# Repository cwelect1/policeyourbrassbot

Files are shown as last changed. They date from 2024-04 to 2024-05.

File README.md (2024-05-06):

# Police Your Brass Bot
A robotics project for <a href="https://courses.dce.harvard.edu/?details&srcdb=202403&crn=34560" target="_blank">DGMD E-17 Spring 2024</a> that collects spent shell casings (brass).

Collecting brass at the firing range is a tedious task that no one seems to enjoy.
There are <a href="https://ammoupusa.com/" target="_blank">manual</a> options that exist to complete the job, but with modern advances in technology an automated solution is in order.

We are taking 2 approaches to prototyping that solution. 
1. Create an RC Car like robot operated via Raspberry PI along with a <a href="https://pixhawk.org/" target="_blank">PixHawk</a> for navigation.
2. Roomba controlled via a Raspberry PI communicating via the serial port.

# Materials - Roomba Implementation
## Hardware
| Qnty | Description |
 | :--- | :--- |
 | 1 pc | Roomba 675 (or similar model with Serial Port)|
 | 1 pc | Raspberry PI 4B (Raspberry PI Zero 2 W will suffice if not adding LIDAR)|
 | 1 pc | <a href="https://www.amazon.com/gp/product/B01N30ZCW9/ref=ppx_yo_dt_b_asin_title_o02_s01?ie=UTF8&psc=1" target="_blank">Logic Level Converter</a> 3.3v <--> 5v between Roomba and RPI|
 | 1 pc | <a href="https://www.amazon.com/Antrader-Breadboard-Dupont-Arduino-Raspberry/dp/B07H9W1NSL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" target="_blank">Jumper wires</a> to connect PI and other hardware|
 | 1 pk | <a href="https://www.adafruit.com/product/2438" target="_blank">Adafruit iRobot Mini-DIN Connector Cable</a> (or Female to Male wires - above)|
 | 1 pc | <a href="https://www.amazon.com/stores/page/CCB1B7D7-B735-4810-ADF3-647B8331BC8B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" target="_blank">Powerbank</a> 2 or more USB portss & 10,000 mAH or more recommended|
 |10 pcs| [5/8" 4-40](https://www.amazon.com/HELIFOUNER-Phillips-Assortment-Threaded-Stainless/dp/B0BNN7YRX8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) pan head screws (Philips worked best for me)|

## Mechanical / 3D Printed
 Most mechanical parts will be 3d printed (Deisgned by this team).<br>
 See the [3d folder](https://github.com/cwelect1/policeyourbrassbot/tree/main/3d).
 | Qnty | Description |
 | :--- | :--- |
 | 1 pc | Roomba Cover (exposes Serial Port) - modified design of <a href="https://www.thingiverse.com/thing:965107" target="_blank">this</a>. |
 |1 pc | Collector Frame - used to attach collector wheel to Roomba |
 |22 pcs | Collector Wheel Tines |
 |20 pcs | Collector Wheel Spacers |
 |1 pc | Collector Wheel Hub |
 |1 pc | Collector Teeth |
 |1 pc | Collector Bin |
 |2 pc | 1/4" diameter dowel 4" long|

## Tools / Misc.
 - Soldering Iron / Solder
 - Drill and bits (1/2", and 5/32")
 - Screw/Hex driver depending on fasteners chosen
 - RPI supplies (Monitor, keyboard, power supply, hdmi adapter/cables)

# Instructions
A few things:
 - Design is based on not opening Roomba or using it's power source
 - RPI and Roomba use different logic levels 0-3.3v and 0-5v respectively (hence the Logic Level Converter)
 - Our concentration is to pick up brass, then work on a proper mapping algorithm

## Hardware
### PI UART (Serial) to Roomba Mini-Din (Serial Port)
In order to communicate with the Roomba, we need to connect to:<br>
<table><tr><td>

- Transmit (TX pin 4)
- Recieve (RX pin 3) 
- Ground (pin 6 or 7)

</td><td>

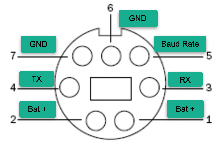
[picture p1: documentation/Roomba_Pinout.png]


</td></tr></table>

Roomba uses 5v logic levels and Raspberry PI 3.3v. To rememdy this difference and not fry the PI, we<br>
utilize the Sparkfun Logic Level Board. We only need 2 of the 4 channels.<br>

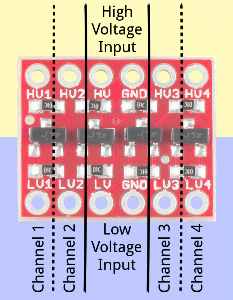
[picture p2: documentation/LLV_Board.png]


### Wiring Diagram
The pinout on RPI Zero, Zero 2, and 4B are all the same.<br>
Here's an example of how to wire the RPI, Logic Level board, and Roomba together.

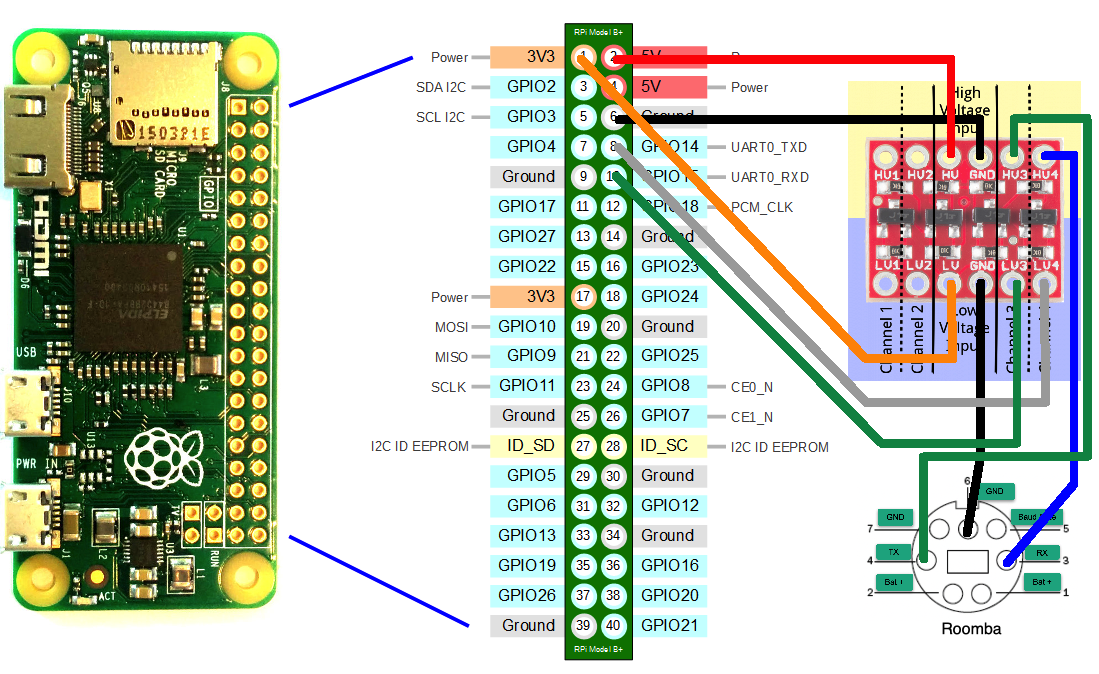
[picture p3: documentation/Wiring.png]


## Software
## Raspberry PI Setup
We are going to interact with the PI as a headless server and don't need the GUI. Ensure that:<br>
 - wifi is setup and working
 - SSH is enabled
 - know your username and pwd (obviously the defaults should be changed)

<a href="https://www.raspberrypi.com/documentation/computers/getting-started.html" target="_blank">Here's</a> a link to the offical RPI Getting Started docs.<br>

### Enable UART on RPI
***You need to REBOOT after this config update*** 
```
cd to /boot/config on the PI

# Comment out the console entry
# console=serial0,115200
#Enable UART if it isn't already enabled

enable_uart=1
```
### Install Required Libraries
1. ssh into the pi using your username@your_rpi's_ip_address
```
ssh pi@192.168.1.1
```
2. Confirm that you have Python 3.6 or higher installed. RPI comes installed with both 2.x and 3.x.
```
python3 -V
```
3. Install <a href="https://pypi.org/project/pyserial/" target="_blank">pyserial</a>. 
```
pip3 install pyserial
```
4. Install <a href="https://atsushisakai.github.io/PyRoombaAdapter/" target="_blank">pyrommbaadapter</a>. 
```
pip3 install pyroombaadapter
```
5. ...and finally...clone our <a href="https://github.com/cwelect1/policeyourbrassbot" target="_blank">repo</a>.
```
git clone git@github.com:cwelect1/policeyourbrassbot.git
```

# Issues / Challenges
 - Roomba to RPI serial communications seems to flake out. We've seen the same python code execute flawlessly once and then fail the very next execution.
 - Roomba wheel encoder(s) not reporting proper values. This has only happened on the Left wheel...and we replaced the whole wheel with same exact results (seems to be serial issue or problem on the main board)
 - Roomba doesn't go straight (ever) - perhaps this is related to bullet above
 - Adding LIDAR turned out to not be possible on RPI Zero. It only has one UART for Serial communication

# What's Next...
 - Work on code to monitor (and react to) sensors while roomba is moving. This has been more challenging then 1st thought
 - Improve 3d parts for fitment
 - Add LIDAR and implement SLAM algorithm for range mapping
 - Add object detection and avoidance

# References
 - Logic Level Board <a href="https://learn.sparkfun.com/tutorials/bi-directional-logic-level-converter-hookup-guide" target="_blank">Hookup Info/Diagram</a>
 - Roomba <a href="https://edu.irobot.com/learning-library/create-2-oi-spec" target="_blank">Open Interface</a> spec

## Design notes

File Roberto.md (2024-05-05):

# Roberto: The Autonomous Rover

## Introduction

Roberto is an autonomous rover designed to navigate and complete missions in a flat-range environment, preferably an indoor or outdoor range with a flat surface like asphalt. This project aims to create a reliable and efficient rover capable of traveling between waypoints while avoiding obstacles.

## Prototype 1: Front-Wheel Drive Rover

The first prototype was a front-wheel drive rover built using a Tupperware container mounted on a 20x20 extruded aluminum frame. It featured 6.5' hoverboard wheels in the front and two caster wheels in the rear, chosen for their ability to navigate a flat range and overcome any casings it might get stuck on. However, this prototype encountered a couple of issues:

- The hoverboard wheels required a specific, expensive ESC, and two cheap ESCs were burned out during testing.
- The components were haphazardly placed inside the container, resulting in a messy wiring situation.

## Prototype 2: RC Chassis-Based Rover (Roberto)

For the second iteration, an RC chassis (INJORA RC Frame Chassis Assembled Frame Chassis for 1/10 RC Crawler SCX10 II) was used as the base for Roberto. The following components were utilized:

- INJORA RC Frame Chassis: [Link](https://www.amazon.com/Assembled-Chassis-Crawler-Upgrades-Without/dp/B07Q11X193?th=1)
- 25KG Digital Servo High Torque: [Link](https://www.amazon.com/ANNIMOS-Digital-Torque-Waterproof-Control/dp/B07GJ6ZCVY)
- GoolRC 60A Brushed ESC Electronic Speed Controller: [Link](https://www.amazon.com/GoolRC-Brushed-Electronic-Controller-Replacement/dp/B0BG4ZB4QD)
- Pixhawk4 (reused from Prototype 1): [Link](https://www.amazon.com/pixhawk-4/s?k=pixhawk+4)
- Readytosky M8N GPS Module (reused from Prototype 1): [Link](https://shorturl.at/lpDU2)
- Raspberry Pi 4 B: [Link](https://www.microcenter.com/product/622539/pi4modelB8gb?src=raspberrypi)
- LiPo battery: [Link](https://shorturl.at/cdrPR)
- LiPo Charger: [Link](https://shorturl.at/dmH26)
- 915Mhz 100MW Radio Telemetry Air and Ground Data Transmit Module: [Link](https://www.amazon.com/YoungRC-Telemetry-Transmit-Pixhawk-Controller/dp/B0C4LBZGRG)
- Flysky Controller and receiver: [Link](https://shorturl.at/DEUV5)
- UBEC Power Module: [Link](https://t.ly/xTYPt)
- Solder Kit: [Link](https://t.ly/piTnM)
- Allen Key set: [Link](https://t.ly/bNFA7)
- M3 assortment set: [Link](https://t.ly/n6eyz)

# Build Process

## 1. Raspberry Pi Configuration

Before assembling Roberto, it is highly recommended that the Raspberry Pi is formatted and configured first. This will save you from the hassle of accessing the SD card in a hard-to-reach spot later on. Start by downloading the appropriate operating system image for your Raspberry Pi model (e.g., Raspberry Pi OS) and write it to the SD card using a tool like Etcher or Raspberry Pi Imager. Once the SD card is ready, insert it into the Raspberry Pi and perform the initial setup, including configuring the Wi-Fi connection, enabling SSH, and updating the system packages. This will allow you to access the Raspberry Pi remotely using SSH from your computer terminal, eliminating the need for physical access to the SD card.

## 2. Chassis Assembly

The RC car chassis serves as the foundation for Roberto. Depending on the specific chassis you purchased, it may come fully assembled or require some assembly. In the case of the INJORA RC Frame Chassis, you will need to install the wheels. Use an Allen key to tighten the screws and ensure that the wheels are securely attached to the chassis. The chassis provides a sturdy base and sufficient ground clearance for Roberto to navigate various terrains.

## 3. Brushed ESC and Motor Connection

Mount the brushed ESC (Electronic Speed Controller) to the motor and establish the necessary connections. Refer to the documentation provided with your ESC and motor to identify the correct wiring configuration. Typically, the ESC will have three wires (positive, negative, and signal) that need to be connected to the corresponding terminals on the motor. Ensure that the connections are secure and properly insulated to prevent short circuits.

## 4. Servo Installation

Install the servo onto the front frame of the chassis. The servo is responsible for steering Roberto. Pay close attention to the alignment and mounting of the servo to ensure that Roberto drives straight. If the installation is not optimal, it can cause Roberto to veer off course. Refer to the servo's documentation for guidance on proper installation and calibration.

## 5. LiPo Battery Connection

Attach the LiPo battery to Roberto's chassis, following the manufacturer's guidelines. Ensure that the battery is securely mounted and the connections are properly made. Double-check the polarity of the battery connections to avoid damage to the components. Before proceeding further, verify that all components are receiving the correct power supply by connecting them to the battery and testing their functionality.

## 6. RC Receiver and Controller Setup

Connect the RC receiver to Roberto and pair it with the Flysky controller. This step is crucial to ensure that you have manual control over Roberto before proceeding with the autonomous setup. Follow the instructions provided with your specific RC receiver and controller to establish the connection. Test the functionality of the controller by moving the joysticks and verifying that Roberto responds accordingly. Having manual control will be invaluable for troubleshooting and testing purposes.

## 7. GPS Module Assembly

Assemble the GPS module and mount it securely on Roberto's chassis. The Injora chassis typically comes with pre-drilled holes that allow you to attach the GPS stand using screws. Ensure that the arrow on the GPS module is pointing towards the front of the vehicle. This orientation is essential for accurate navigation. If the GPS stand is damaged or broken, you can temporarily use a 3D-printed replacement until you can obtain a new one.

## 8. Pixhawk and Raspberry Pi Integration

Connect the Pixhawk flight controller and Raspberry Pi to Roberto's chassis and establish the necessary connections between the components. Refer to the documentation provided by the manufacturers for detailed instructions on wiring and configuration. The Pixhawk typically has dedicated ports for GPS, telemetry, and other peripherals. Make sure to connect the components to the correct ports to ensure proper communication and functionality. The Raspberry Pi will serve as the companion computer, running the necessary software for autonomous navigation and control.

## 9. Cable Management

Use electrical tape and cable ties to keep the wiring tidy and organized. Route the cables neatly along the chassis, avoiding any moving parts or potential snag points. A clean and well-managed wiring setup not only improves the aesthetics of Roberto but also reduces the risk of loose connections or damage to the cables during operation.

## 10. Telemetry Module and Mission Planner

Install the telemetry module on Roberto and configure it to establish a connection with Mission Planner. The telemetry module enables wireless communication between Roberto and your computer, allowing you to monitor its status, send commands, and receive telemetry data. Follow the documentation provided with your telemetry module to set up the connection properly. Once connected, you can use Mission Planner to plan waypoints, monitor Roberto's progress, and analyze telemetry data.

# Setting up Autonomous Missions

1. **SSH into the Raspberry Pi:** To establish a secure connection with the Raspberry Pi, use the SSH protocol. Open your computer's command terminal and enter the following command: 
    ```
    ssh username@raspberrypi_ip_address
    ```
    Replace `username` with the username you set up during the formatting of the Raspberry Pi, and `raspberrypi_ip_address` with the IP address assigned to your Raspberry Pi. When prompted, enter the password you configured during the setup process. If you have forgotten your credentials, you may need to reformat the Raspberry Pi and set up a new username and password.

2. **Download Python files and install libraries:** Once you have successfully logged into the Raspberry Pi via SSH, navigate to the directory where you want to store your Python files. Use the following command to download the necessary files from the GitHub repository: 
    ```
    git clone https://github.com/your_repository_url
    ```
    Replace `your_repository_url` with the URL of the GitHub repository containing the required Python files for your autonomous mission. After downloading the files, navigate to the project directory and install the required libraries. You can typically do this using the pip package manager. For example: 
    ```
    pip install dronekit
    pip install pymavlink
    ```

3. **Create a virtual environment (optional):** In some cases, you may need to create a virtual environment to avoid conflicts with existing Python libraries. To create a virtual environment, use the following command: 
    ```
    python3 -m venv myenv
    ```
    Replace `myenv` with your desired name for the virtual environment. To activate the virtual environment, run: 
    ```
    source myenv/bin/activate
    ```
    Once activated, you can install the necessary libraries within the virtual environment using pip as mentioned in step 2.

4. **Navigate to the Python files:** Use the `cd` command to navigate to the directory where your Python files are located. For example: 
    ```
    cd /path/to/your/python/files
    ```
    Replace `/path/to/your/python/files` with the actual path to the directory containing your Python files.

5. **Run the connection test:** To ensure that the Raspberry Pi is properly connected to the Pixhawk and ready for autonomous missions, run the `connection_test.py` file. Use the following command: 
    ```
    python connection_test.py
    ```
    If the connection is successful, you should see a message indicating that the Raspberry Pi is connected to the Pixhawk and ready to receive commands.

6. **Edit the location-based movement file:** Open the `location_based_movement.py` file using the nano text editor with the following command: 
    ```
    nano location_based_movement.py
    ```
7. **Inside the file, locate the section where you need to specify the GPS coordinates of your waypoints.*** Enter the latitude, longitude, and altitude for each waypoint in the format specified in the file. For example: 
    ```
    waypoints = [

        (latitude1, longitude1, altitude1),

        (latitude2, longitude2, altitude2),

        # Add more waypoints as needed

    ]
    ```
    Save the changes by pressing Ctrl+X, then Y, and finally Enter.

7. **Run the location-based movement file:** To start the autonomous mission, run the location_based_movement.py file using the following command: 
    ```
    python location_based_movement.py
    ```
    The rover should now begin navigating to the specified waypoints autonomously. Monitor the progress of the mission through the command terminal or any connected telemetry software like Mission Planner. If the rover successfully reaches all the waypoints, congratulations! You have successfully set up and executed an autonomous mission.

    Remember to always prioritize safety and follow proper precautions when working with autonomous vehicles. Ensure that you have a clear line of sight to the rover and are ready to take manual control if necessary. DO NOT attempt to do this on a street, your Rover may run away and get crushed by a car.

# Challenges and Solutions

## Challenge: Difficulty in connecting the Pixhawk to the Raspberry Pi.
**Solution:** Ensure that you have the correct wiring connections between the Pixhawk and Raspberry Pi. Refer to the wiring diagrams and documentation specific to your Pixhawk model. Double-check the pin assignments and make sure the connections are secure. If you're still having issues, try using a different USB cable or port on the Raspberry Pi.

## Challenge: Issues with the Raspberry Pi not booting or not being accessible via SSH.
**Solution:** First, make sure that the Raspberry Pi is properly powered and the power supply is sufficient. Check if the LED lights on the Raspberry Pi are indicating any activity. If the issue persists, try reformatting the SD card and reinstalling the operating system. Ensure that SSH is enabled in the Raspberry Pi configuration settings.

## Challenge: The rover is not moving or responding to commands.
**Solution:** Check the battery connections and ensure that the rover is properly powered. Verify that the ESC and motor connections are correct and secure. Make sure that the RC receiver is properly bound to the transmitter and the channels are configured correctly. Use the `connection_test.py` script to confirm the communication between the Raspberry Pi and the Pixhawk.

## Challenge: The rover is not following the specified waypoints accurately.
**Solution:** Ensure that the GPS module is properly connected and has a clear view of the sky. Verify that the GPS coordinates of the waypoints are accurate and entered correctly in the `location_based_movement.py` file. Check the GPS status in Mission Planner or other telemetry software to confirm that the rover is receiving a valid GPS signal.

## Challenge: The rover is behaving erratically or not stabilizing during autonomous missions.
**Solution:** Make sure that the Pixhawk is properly calibrated, including the accelerometer, compass, and radio calibration. Follow the calibration procedures outlined in the Pixhawk documentation. Check the PID tuning parameters and adjust them if necessary to achieve stable flight behavior.

## Challenge: Difficulty in installing required libraries or dependencies.
**Solution:** Double-check that you are using the correct version of Python and pip. Ensure that you have a stable internet connection to download the necessary packages. If you encounter conflicts with existing libraries, consider creating a virtual environment to isolate the project dependencies. Consult the documentation or forums for the specific library you are having trouble with.

## Challenge: The rover loses connection or telemetry data during the mission.
**Solution:** Check the telemetry module connections and ensure that the antennas are securely attached. Verify that the telemetry settings in Mission Planner or other ground control software match the settings on the rover. Ensure that the rover is within the range of the telemetry module and there are no obstructions interfering with the signal.

## Challenge: The code is not running or throwing errors.
**Solution:** Double-check the syntax and indentation of your Python code. Verify that all the required libraries are imported correctly. Check for any missing dependencies or incompatible versions. Consult the error messages and traceback to identify the specific line or section causing the issue. Seek help from forums, documentation, or the robotics community if needed.

## Author Information

- **Author:** Grigori A. Lopez-Garcia
- **Major:** Digital Media Design
- **University:** Harvard Extension
- **Graduation Year:** 2023
- **Email:** grl322@g.harvard.edu

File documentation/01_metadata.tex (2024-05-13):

% 01_metadata.tex
% this .tex file vcovers everything from the heading down to the keyterms and footnaotes on the first page. the rest is managed at the main.tex file.

\newcommand{\Journal}{Technical Documentation}
\newcommand{\Year}{2024}
\newcommand{\Month}{May}

\newcommand{\Volume}{I}
    \newcommand{\vol}{Vol. ~\Volume}
    \newcommand{\Vol}{VOLUME~\Volume}

\newcommand{\Number}{I}
\newcommand{\TITLE}{Brass Bot : Technological Framework for Collecting Spent Cartridges}
\newcommand{\Title}{Brass Bot}
\newcommand{\TitleFoot}{\footnote[2]{Submission for \href{https://courses.dce.harvard.edu/?details&srcdb=202403&crn=34560}{DGMD $E-17$} Spring Academic Term of 2024.}}

\newcommand{\AUTHOR}{LopezGarcia, G. Ross, D. Weinberg, C.}
\newcommand{\AuthorFoot}{\footnote[1]{Grigori LopezGarcia ALM, Donald Ross ALB, Corbett Weinberg ALB}}

\newcommand{\ABSTRACT}{This project professes the challenge of designing and prototyping an autonomous device that will collect the spent cartridges that have already been ejected from a firearm and are on the floor of a firing range.

Two distinct prototypes were developed one by Grigori LopezGarcia, the seconded by Corbett Weinberg. These prototypes were designed considering the unique constraints posed by remote collaboration and geographical dispersion of a team member. Through iterative design, integration of feedback from multiple hardware tests, the project encapsulates -- working prototypes that were a focused designed on the physical hardware. Through its triumph's and failures the difficulty of the hardware process. For better, or for worse, no simulators were used in the creation of this robot.}

\newcommand{\KEYWORDS} {Three Dimensional Printing, Autonomous Robotics, Firearm-Safety, Innovative Technologies, Material Recovery, Python}

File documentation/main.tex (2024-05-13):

% main.tex
\documentclass{scrarticle}
\input{00_preamble}
\input{01_metadata}
\begin{document}
\setcounter{page}{000}
\input{02_title}
%%% from this comment down we can start to write code taht will influence how our paper will look... the abstract is afterall the last thing we would write. 
\drop This documentation discusses the challenges: 'practical and academic' work done for the final project\ldots We go through the lens taken for the project, a guide of our production process, the hardware and software used, our results, and the continued.  
\section{Preface}
Prototyping of the two autonomous devices that are designed to collect spent brass\footnote{ejected firearm cartridges} in an indoor professional range of local, county, or state police officers.\footnote{{specifically United States Police Officers}} The remote nature of this courses' iteration, and a classmates geographic skisim from Cambridge - Massachusetts and necessitated the creation of separate hardware prototypes. This complicated our work but it did not over-engineer it. It gave us the abiltiy to replicate the difficulties of working with a scattered team across the country with different hardware.   

\section{Background}
\subsection{ Cops, Engineers, and Lobbyist}
LopezGarcia$'$s is the originator of the project -- His professional use of firearms brought regulated material into aproject that forced Ross and Weinberg to familiarize themselves with Massachusetts firearms regulations and creating alternatives for testing a robot that is supposed to use ammunition in a highly regulated and professional environment-- this is to say we used 3d printed stand ins for spent cartridges. Ross held to the majority of the bureaucratic administrative tasks and supervised the video production projects. Weinberg brought extensive engineering and fabrication experience, fabricating. 

\subsection{Starting with a Problem}
LopezGarcia identified the practicality of automating spent cartridges in a professional and sporting environment.\footnote{A single day of firearm training in a Police department can eject thousands of spent cartridges onto the gun-range.}
We began by using the legal patent as academic inspiration for a device that is able to collect spent brass.\footnote{AmmoUP LLC, ``Device for Collecting Spent Cartridges,'' U.S. Patent No US-20150264865-A1, 2015. Available online: \url{https://ppubs.uspto.gov/dirsearch-public/print/downloadPdf/20150264865}} Due to this inspiration, two distinct robot prototypes were created: `Roberto,' by LopezGarcia, and `Brassbot,' by Weinberg. Additionally, the commercial product by AmmoUp, LLC, started our design.\footnote{AmmoUp, LLC, ``Products for Rifle and Pistol Brass Collection,'' 2024. Accessed April 1st, 2024. \url{https://ammoupusa.com/product-cat/products/rifle-and-pistol-brass/}} Originally designed to pick up nuts, it has been sold and adapted to collect brass bullet casings professionally by the Delaware Police Department and multiple Delaware private firearms clubs. The project's goal was to assess the feasibility of automating the spent brass.

\section{Methodology}
In this section we expand on the hardware production of  the prototypes. The manufacturing the devices and the hardware used. We will discuss software components in software in Section {\textbf{IV. Computer Software}}. See Figure \ref{fig:img7299} and Figure \ref{Figure 4} for the assembled prototypes. 

%%%Gargia's Robot
\subsection{Duck Tape and Tupperware}
LopezGarcia$'$s 1$^{st}$ prototype, was a front wheel drive mounted onto a $20x20$ extruded aluminum frame taped with a transparent Tupperware enclosure, and 6.5' hoverboard wheels on front and caster wheels at the Tupperware's rear. Each of the four wheels were independently controlled by its ESC and managed by a Pixhawk controller stashed inside the Tupperware. Two problems arose from the Tupperware prototype. While justifying separate ESCs for fine control and fiscal budgeting was undermined by the wheels' fragile exterior and interior. A necessity for higher-quality ESCs, the Tupperware's crosswired enclosure, GPS, compass readings, and persistent trouble with hoverboard wheels and ESCs culminating in the failure of an ESC and a potential risk of damage to the entire micro controller setup. For image of the device see Figure \ref{fig:untitled1}.

\begin{figure}[h]
  \centering
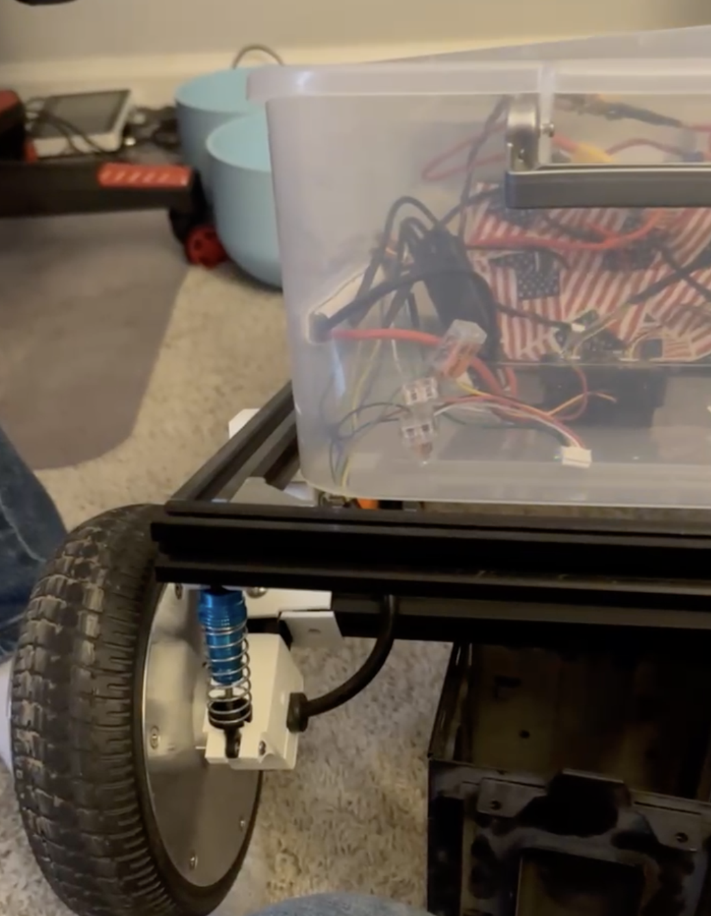
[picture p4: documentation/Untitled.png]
  
  \caption{A photo of GrigorLopez's Tumpperware prototype$'$s rear caster wheels.}
  \label{fig:untitled1}
\end{figure}

The $2^{nd}$ version uses a steel RC car chassis, $1/10$ scale frame, a dramatic improvement from the previous Prototype. The transition to the RC chassis necessitated component replacement, and the calibration process was extensive. This chassis achieved success limited autonomous functionality using Mission Planner as can be seen below. 

Or see the Figure \ref{fig:img7299}. 

\begin{figure}[h]
  \centering
  
  \caption{The seconded prototype on the RC Chasis}
  \label{fig:img7299}
\end{figure}

Roberto is an autonomous rover designed to navigate and complete missions in a flat-range environment, preferably an indoor or outdoor range with a flat surface like asphalt. This project aims to create a reliable and efficient rover capable of traveling between waypoints while avoiding obstacles.

\subsection{The Tupperware Rover}
The first prototypes' unqiue pieces of hardware that were not used in the second robot were:
\begin{itemize}
    \item The hoverboard wheels required a specific, expensive ESC, and two cheap ESCs were burned out during testing.
    \item The components were haphazardly placed inside the container, resulting in a messy wiring situation.
\end{itemize}

\subsection{Prototype 2: RC Chassis-Based Rover (Roberto)}
For the second iteration, an RC chassis was used as the base for Roberto, the Major enhanced purchases:

\begin{itemize}
    \item \textbf{Chassis}: INJORA RC Frame Chassis. 
    \item \textbf{Servo}: 25KG Digital Servo High Torque for precise control. 
    \item \textbf{ESC}: GoolRC 60A Brushed ESC for reliable power management. 
    \item \textbf{Computational Control}: Raspberry Pi 4 B and Pixhawk4 reused from the $1^{st}$ prototype for advanced control and navigation. 
\end{itemize}

\subsection{Assembly of the Second Prototype}
Before assembling Roberto, it is crucial to format and configure the Raspberry Pi. This preparation allows for remote access via SSH, eliminating the need for physical SD card access post-assembly. The setup involves downloading the Raspberry Pi OS, writing it to the SD card, and performing initial configurations including Wi-Fi and SSH setup.

\subsubsection{Chassis Assembly}
The RC car chassis forms the base of Roberto. Assembly varies by model; our INJORA RC Frame Chassis required manual wheel installation, emphasizing the importance of secure attachments for robust navigation.

\subsubsection{Brushed ESC and Motor Connection}
Connecting the Electronic Speed Controller (ESC) to the motor involves precise wiring—positive, negative, and signal lines must be securely connected and insulated to prevent electrical faults.

\subsubsection{Servo Installation}
The servo, critical for steering, is mounted on the front frame. Correct installation is crucial for accurate navigation, requiring careful alignment and calibration.

\subsubsection{LiPo Battery Connection}
The LiPo battery is attached to the chassis, ensuring secure mounting and correct polarity connections.

\subsubsection{RC Receiver and Controller Setup}
The RC receiver is paired with the Flysky controller, establishing manual control essential for initial testing and troubleshooting.

\subsubsection{GPS Module Assembly}
The GPS module is mounted on the chassis with the orientation marker pointing forward, critical for accurate positional data.

\subsubsection{Pixhawk and Raspberry Pi Integration}
Integration of the Pixhawk flight controller with the Raspberry Pi involves detailed wiring and configuration to ensure effective communication between navigation components and the control software.

\subsubsection{Telemetry Module and Mission Planner}
The telemetry module is installed and configured to communicate with Mission Planner, enabling remote monitoring and command transmission for waypoint navigation and data analysis.

\subsection{BrassBot Roomba}

\subsubsection{Materials - Roomba Implementation}

\paragraph{Hardware}
\begin{itemize}
    \item \textbf{1 pc} Roomba 675 (or similar model with Serial Port)
    \item \textbf{1 pc} Raspberry PI 4B (Raspberry PI Zero 2 W will suffice if not adding LIDAR)
    \item \textbf{1 pc} Logic Level Converter 3.3v <--> 5v between Roomba and RPI
    \item \textbf{1 pc} Jumper wires to connect PI and other hardware
    \item \textbf{1 pk} Adafruit iRobot Mini-DIN Connector Cable (or Female to Male wires)
    \item \textbf{1 pc} Powerbank with 2 or more USB ports \& 10,000 mAH or more recommended
    \item \textbf{10 pcs} 5/8" 4-40 pan head screws (Philips worked best)
\end{itemize}

\paragraph{Mechanical / 3D Printed}
Most mechanical parts will be 3D printed (designed by this team). See the 3D folder for more details.\footnote{\href{https://github.com/cwelect1/policeyourbrassbot/tree/main/3d}{https://github.com/cwelect1/policeyourbrassbot/tree/main/3d}} And see Figure \ref{Figure 3} for the completed printed rolling mechanism.
\begin{itemize}
    \item \textbf{1 pc} Roomba Cover (exposes Serial Port) - modified design
    \item \textbf{1 pc} Collector Frame - used to attach collector wheel to Roomba
    \item \textbf{22 pcs} Collector Wheel Tines
    \item \textbf{20 pcs} Collector Wheel Spacers
    \item \textbf{1 pc} Collector Wheel Hub
    \item \textbf{1 pc} Collector Teeth
    \item \textbf{1 pc} Collector Bin
    \item \textbf{2 pc} 1/4" diameter dowel, 4" long
\end{itemize}

\begin{figure}
    \centering
    
    \caption{3-D printed Brass collection mechanism}
    \label{Figure 3}
\end{figure}

\paragraph{Tools / Misc.}
\begin{itemize}
    \item Soldering Iron / Solder
    \item Drill and bits (1/2", and 5/32")
    \item Screw/Hex driver depending on fasteners chosen
    \item RPI supplies (Monitor, keyboard, power supply, HDMI adapter/cables)
\end{itemize}

\subsubsection{Instructions}

\paragraph{Design Considerations}
The design is based on not opening the Roomba or using its power source. The Raspberry Pi and Roomba use different logic levels (0-3.3V and 0-5V, respectively), hence the need for a Logic Level Converter. Our initial focus is on picking up brass, with subsequent work on developing a proper mapping algorithm.
\begin{figure}
    \centering
    
    \caption{The Fully Assembled Brassbot Prototype}
    \label{Figure 4}
\end{figure}
\paragraph{Hardware Connection}
\begin{itemize}
    \item \textbf{PI UART (Serial) to Roomba Mini-Din (Serial Port)}
        \begin{itemize}
            \item Transmit (TX pin 4)
            \item Receive (RX pin 3)
            \item Ground (pin 6 or 7)
        \end{itemize}
    \item Roomba uses 5V logic levels, and Raspberry Pi uses 3.3V. To remedy this difference and protect the Pi, we utilize the Sparkfun Logic Level Board, using only 2 of the 4 channels.
\end{itemize}

\paragraph{Wiring Diagram}
The pinout on RPI Zero, Zero 2, and 4B are the same. The provided diagram illustrates how to wire the RPI, Logic Level board, and Roomba together.

Raspberry PI 4B 

%%% this is the software section 

\section{Computer Software}
\subsection{Roberto:Setting Up Autonomous Missions}
This subsection explains the steps required to establish a secure connection to the Raspberry Pi, set up the necessary software, and deploy the rover for autonomous navigation using a Pixelhawk Controller. We suggest watching LopezGarcia$'$s demo first and then continue reading the docuement.\footnote{\href{https://www.youtube.com/watch?v=ZlEQnen6U_s}{https://www.youtube.com/watch?v=ZlEQnen6U_s}}

\subsubsection{SSH into the Raspberry Pi}
To initiate a secure SSH connection to the Raspberry Pi, open your computer's terminal and enter the command:
\begin{verbatim}
ssh username@raspberrypi_ip_address
\end{verbatim}
Replace \textit{username} with your configured username and \textit{raspberrypi\_ip\_address} with the IP address assigned to your Raspberry Pi. The Pi is critical --  without it there is no connection to the device.Downloading and Installing Software.Once connected, download the required Python files from your GitHub repository using:
\begin{verbatim}
git clone https://github.com/your_repository_url
\end{verbatim}
Replace \textit{your\_repository\_url} with the actual URL. Install necessary Python libraries with pip:
\begin{verbatim}
pip install dronekit
pip install pymavlink
\end{verbatim}

\subsubsection{Setting Up a Virtual Environment (Optional)}
For environments requiring specific dependencies, set up a virtual environment:
\begin{verbatim}
python3 -m venv myenv
source myenv/bin/activate
\end{verbatim}
This environment isolates library installations and configurations, preventing conflicts.

\subsubsection{Running Connection Tests and Setting Waypoints}
Before launching autonomous missions, ensure the rover's systems are communicating effectively:
\begin{verbatim}
python connection_test.py
\end{verbatim}
Edit the \textit{location\_based\_movement.py} file to set GPS coordinates for the mission waypoints:
\begin{verbatim}
nano location_based_movement.py
\end{verbatim}
List the waypoints directly within the file, ensuring each is correctly formatted.

\subsubsection{Launching the Autonomous Mission}
Execute the autonomous mission script:
\begin{verbatim}
python location_based_movement.py
\end{verbatim}
Monitor the rover's progress through the command terminal or telemetry software, adjusting settings or correcting issues as needed.

\paragraph{Safety and Precautions}
Always ensure a clear line of sight to the rover during operations and be ready to assume manual control if necessary. Avoid using the rover near streets or unsafe terrains to prevent accidents.

\subsection{Brassbot's Roomba and Pi Software Setup}
\paragraph{Initial Raspberry Pi Configuration}
Ensure the Raspberry Pi is configured to operate without a GUI, focusing on headless server use:
\begin{itemize}
    \item Ensure WiFi is operational.
    \item Enable SSH for remote access.
    \item Update the default username and password for security.
\end{itemize}
Refer to the official Raspberry Pi documentation \footnote{\url{https://www.raspberrypi.org/documentation/}} for detailed setup instructions.

\paragraph{Enable UART}
Modify the boot configuration to enable UART:
\begin{verbatim}
# Navigate to the boot config directory
cd /boot/config
# Edit the configuration file
# Disable console over serial
# Enable UART
enable_uart=1
\end{verbatim}

\paragraph{Install Required Libraries}
Use SSH to install necessary Python libraries for serial communication:
\begin{verbatim}
# SSH into the Pi
ssh pi@<your_rpi_ip_address>
# Install pyserial
pip3 install pyserial
# Install pyroombaadapter
pip3 install pyroombaadapter
# And clone the repository 
 git clone git@github.com:cwelect1/policeyourbrassbot.git
\end{verbatim}

%%
%%
%%%
%%%%%% results section 
\section{Results}
All rough prototyping is finished and there is organic moral to continue the project. Sensoring issues,  
\subsection{Challenges, Solutions, and Steps Foward}

LopezGarcia : Initially, I wanted to use an Xbox Controller, but Mission Planner will not recognize it. As an alternative, I opted for a Flysky controller and realized that I needed a receiver and a telemetry module. Luckily, I had used the same receiver and module in the first iteration, so I was able to recycle these parts. Another challenge I faced was that the Raspberry Pi was located in a hard-to-reach spot. To configure it, I had to remove the SD card using a pair of tweezers. Eventually, I decided to go with a headless approach and SSH into the Pi from my computer terminal. Once I was able to configure the Pi, I set up the Mission Control application and connected the Rover. After a few calibration hiccups, I ran a Python script to verify that the Pi and the Pixhawk could communicate, and I received a positive message confirming the connection.

Weinberg : Roomba to RPI serial communications seems to flake out. We've seen the same python code execute flawlessly once and then fail the very next execution.
Roomba wheel encoder(s) not reporting proper values. This has only happened on the Left wheel...and we replaced the whole wheel with same exact results (seems to be serial issue or problem on the main board)
Roomba doesn't go straight (ever) - perhaps this is related to bullet above
Adding LIDAR turned out to not be possible on RPI Zero. It only has one UART for Serial communication which made LIDAR currently unfeasable. 

\section{Next Steps}
Sensor issues impacting both Roberto and BrassBot must be resolved before we can proceed with further development. We are experiencing issues with wheel odometry where data seems to be getting lost, misinterpreted, or manipulated during transmission from the Roomba Pi to the laptops remotely controlling the Pi. Additionally, there is a need to clarify roles and define ownership more distinctly.

\subsection{LopezGarcia -- Where we go from here}
In advancing this project, I am prioritizing the optimization of the Mission Planner's waypoints and conducting a thorough reassessment of our wheel odometry systems to rectify the persistent inaccuracies.
In addition to refining navigation systems and sensor accuracy, I am prioritizing the development of a more robust and durable chassis for our prototypes, as Roberto is currently exposed and laid bare. Given the demanding conditions of a firearm range, where durability and resilience are paramount, crafting a sturdier chassis is crucial. The shooting range environment, with its high potential for debris, vibrations, and impacts, requires a framework that can protect sensitive electronics.

\subsection{Ross -- Where we go from here}
My venture-oriented 2L colleague at HLS has seen good ideas destroyed through handshake deals no clear structure. The most significant administrative challenge is ensuring proper legal and operational structures if we are to continue collaborating effectively. One of our most significant administrative challenges is ensuring that we establish proper legal and operational frameworks to support effective collaboration. Historically, the absence of formal agreements and defined ownership has led to the failure of many potential ventures. We have tentatively planned to further discuss the project as the summer term progresses. Additionally, I am reaching out to my colleagues at HLS to arrange the biannual pro-bono incorporation workshop at the HI-lab/HLS this coming Sunday evening (May 12). My goal is to have drafted articles of incorporation, and solidify stakeholder positions.  Creating the structure, and secure foundation for our project.

\subsection{Weinberg -- Where we go from here}
The most pressing issue is the Roomba's deviation from the pre-programmed course. We need to investigate how the monitors and sensors are transmitting data while the Roomba is in motion. Additionally, we must assess the feasibility of integrating an additional LiDAR camera to enable the implementation of a SLAM algorithm for range mapping. Finally, improvements are needed in the 3D printed brass collection mechanism.
%%% conclusing remarks 
\section{Conclusion}

The success of the "Brass Bot" project is deeply anchored in the focused vision brought by Grigori LopezGarcia, whose practical insights into the specific needs of firing ranges were instrumental. This project not only showcased the feasibility of automating the collection of spent cartridges but also demonstrated the impact of targeted, knowledgeable leadership in the production process.

\section{Conclusion}
The project not only showcased the feasibility of automating the collection of spent cartridges but also demonstrated the impact of targeted, knowledgeable leadership in the production process. This initiative not only resolves a logistical challenge but also paves the way for enhancing operational efficiencies in law enforcement training environments. By integrating advanced robotics with strategic project management, the project has established a prototype that could potentially redefine standard maintenance procedures in shooting facilities. The success of this project underscores the significant impact of combining domain-specific knowledge with technological innovation, leading to a promising avenue for future advancements in automated systems.

\section{Bibliography}
\begin{thebibliography}{9}
\bibitem{PoliceAmmoUsage2024}
Anonymous, ``Estimation of Ammunition Usage,'' 2024. Data provided by a local police department on their annual ammunition usage for training purposes.

\bibitem{LopezGarciaPatent}
Lopez Garcia, Grigori, ``Device for Collecting Spent Cartridges,'' U.S. Patent No. US-20150264865-A1, 2015. Available online: \url{https://ppubs.uspto.gov/dirsearch-public/print/downloadPdf/20150264865}.

\bibitem{AmmoUp2024}
AmmoUp, LLC, ``Products for Rifle and Pistol Brass Collection,'' 2024. Accessed April 1, 2024. \url{https://ammoupusa.com/product-cat/products/rifle-and-pistol-brass/}.
\end{thebibliography}

\section{Additional Resources}
\begin{itemize}
    \item \textbf{Our GitHub Repository:} \url{https://github.com/cwelect1/policeyourbrassbot}
    \item \textbf{Logic Level Board Hookup Info/Diagram:} \url{https://learn.sparkfun.com/tutorials/bi-directional-logic-level-converter-hookup-guide}
    \item \textbf{Roomba Open Interface Specs:} \url{https://edu.irobot.com/learning-library/create-2-oi-spec}
\end{itemize}
\end{document}

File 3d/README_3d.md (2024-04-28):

# Police Your Brass Bot - 3d Model Info

# Printers
|<a href="https://bambulab.com/en/p1" target="_blank">P1S</a>|<a href="https://qidi3d.com/products/qidi-x-max-3" target="_blank">XMAX3</a>|
|:---:|:---:|
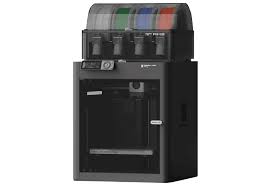
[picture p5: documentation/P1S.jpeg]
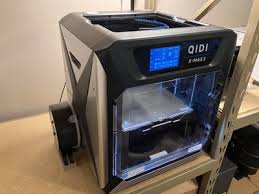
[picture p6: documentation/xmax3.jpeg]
||| 

# Model Settings
### PLA+ Files
<table>
<tr><th>RoombaCover.stl </th><th>Frame.stl</th><th>WheelHub.stl</th></tr>
<tr><td>

|Setting| Value |
|--|--|
|Material | PLA+ |
|Layer Hgt | 0.2 |
|Infill | 100% |
|Support | None |
|Walls | 4|

</td><td>

|Setting| Value |
|--|--|
|Material | PLA+ |
|Layer Hgt | 0.2 |
|Infill | 100% |
|Support | None |
|Walls | 4|
</td><td>

|Setting| Value |
|--|--|
|Material | PLA+ |
|Layer Hgt | 0.2 |
|Infill | 100% |
|Support | None |
|Walls | 4|

</td></tr> </table>

### TPU Files
<table>
<tr><th>WheelTine.stl </th><th>WheelTineSpacer.stl</th></tr>
<tr><td>

|Setting| Value |
|--|--|
|Material | TPU |
|Layer Hgt | 0.2 |
|Infill | 25% |
|Support | Build Plate |
|Walls | 4|
|Cleanup| Remove support|

</td><td>

|Setting| Value |
|--|--|
|Material | TPU |
|Layer Hgt | 0.2 |
|Infill | 100% |
|Support | None |
|Walls | 4|
|Cleanup | Remove mouse ears|

</td></tr> </table>

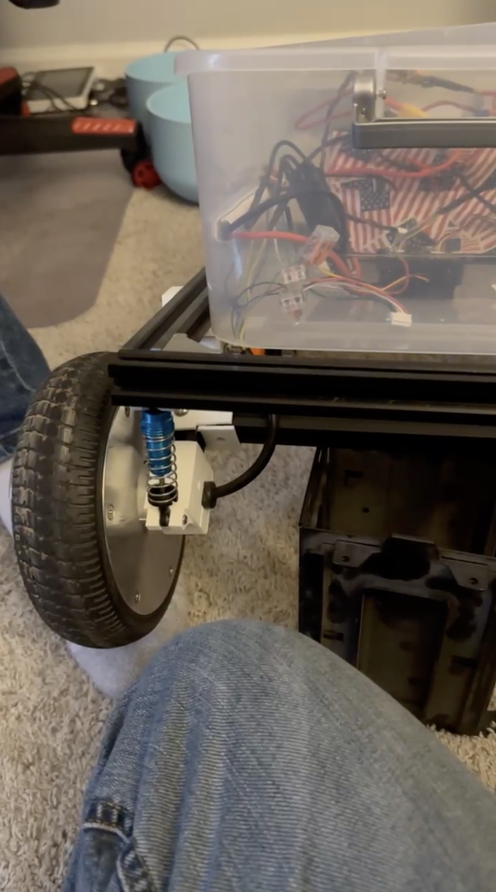
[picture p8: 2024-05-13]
documentation/tumppleware.png

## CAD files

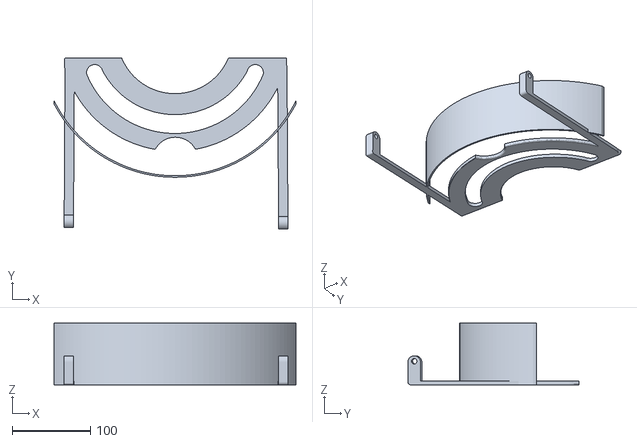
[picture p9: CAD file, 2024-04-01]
3d/Frame.stl
309.0 x 218.6 x 79.0

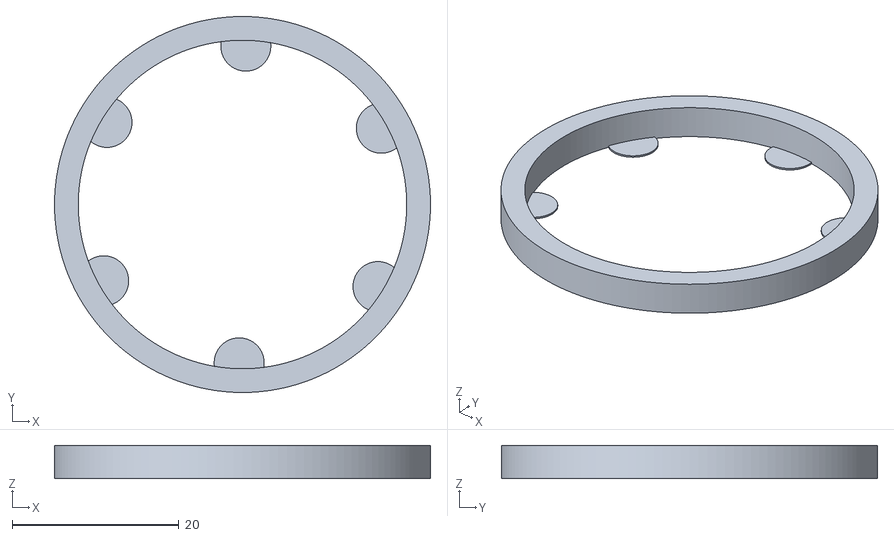
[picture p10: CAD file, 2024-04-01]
3d/WheelTineSpacer.stl
45.1 x 45.1 x 4.00

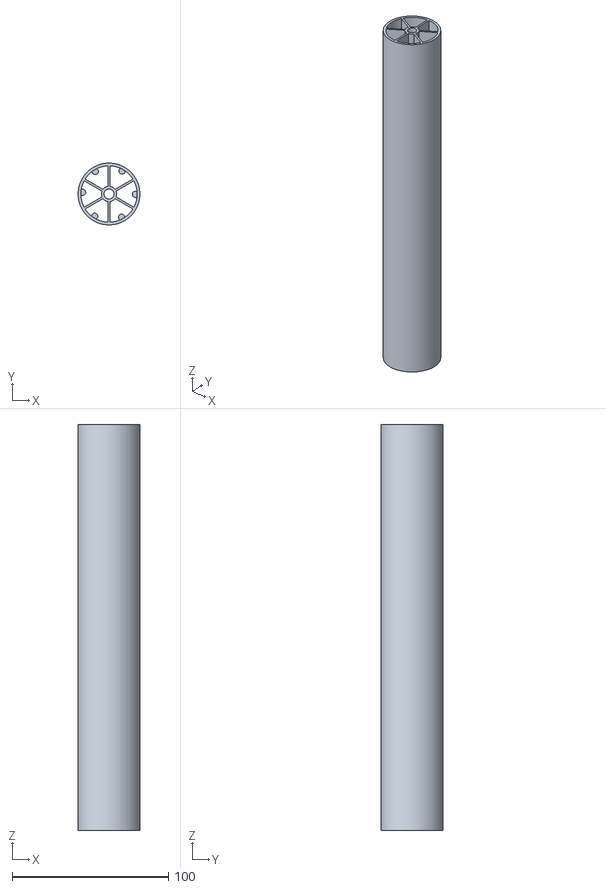
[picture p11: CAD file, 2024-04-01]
3d/WheelHub.stl
39.6 x 39.6 x 260.0

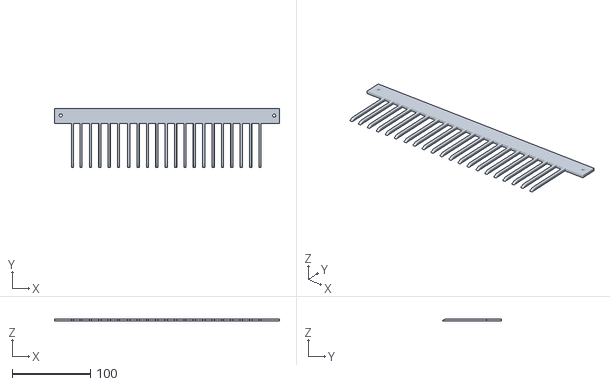
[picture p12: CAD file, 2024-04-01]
3d/CollectorTeeth.stl
288.0 x 75.7 x 3.00

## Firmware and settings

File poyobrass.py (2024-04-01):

from PyRoombaAdapter import PyRoombaAdapter

def main():
    PORT = "/dev/ttyUSB0"
    adapter = PyRoombaAdapter(PORT)
    # adapter.send_drive_cmd(-100, -1000)
    # adapter.send_drive_direct(-100, 100)
    import math
    # adapter.move(0.1, math.radians(-10))
    # adapter.send_drive_pwm(80, 80)
    # adapter.send_drive_pwm(-200, -200)
    # adapter.send_moters_cmd(False, True, True, True, False)
    # adapter.send_pwm_moters(-55, -25, 25)
    # adapter.send_buttons_cmd(dock=True)
    # sleep(1.0)

    adapter.move(0.2, math.radians(0.0))
    sleep(1.0)
    adapter.move(0, math.radians(-20))
    sleep(6.0)
    adapter.move(0.2, math.radians(0.0))
    sleep(1.0)
    adapter.move(0, math.radians(20))
    sleep(6.0)

    # adapter.move(-0.1, 0)
    # sleep(1.0)


if __name__ == '__main__':
    main()

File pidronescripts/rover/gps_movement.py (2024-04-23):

##########DEPENDENCIES#############

from dronekit import connect, VehicleMode, LocationGlobalRelative, APIException
# Import necessary modules from the dronekit library

import time
# Import the time module for adding delays

import socket
# Import the socket module for network communication

# import exceptions
# Commented out the import of exceptions module as it is not used in the code

import math
# Import the math module for mathematical calculations

import argparse
# Import the argparse module for parsing command-line arguments

#########FUNCTIONS#################

def connectRoberto():
    # Function to connect to the vehicle (drone) using command-line arguments
    parser = argparse.ArgumentParser(description='commands')
    parser.add_argument('--connect', help='Connection string for the vehicle')
    args = parser.parse_args()
    connection_string = args.connect
    # Parse the connection string from command-line arguments
    
    vehicle = connect(connection_string, wait_ready=True, baud=57600)
    # Connect to the vehicle using the provided connection string and baud rate
    # wait_ready=True ensures that the script waits until the vehicle is ready
    
    return vehicle
    # Return the connected vehicle object

def arm():
    # Function to arm the vehicle and set it to GUIDED mode
    while not vehicle.is_armable:
        print("Waiting for vehicle to become armable.")
        time.sleep(1)
    # Wait until the vehicle becomes armable
    
    print("Vehicle is now armable")
    
    vehicle.mode = VehicleMode("GUIDED")
    while vehicle.mode != 'GUIDED':
        print("Waiting for drone to enter GUIDED flight mode")
        time.sleep(1)
    # Set the vehicle mode to GUIDED and wait until it is in GUIDED mode
    
    print("Vehicle now in GUIDED MODE. Have fun!!")
    
    vehicle.armed = True
    while not vehicle.armed:
        print("Waiting for vehicle to become armed.")
        time.sleep(1)
    # Arm the vehicle and wait until it is armed
    
    print("Vehicle is now armed.")
    return None

def get_distance_meters(targetLocation, currentLocation):
    # Function to calculate the distance in meters between two locations
    dLat = targetLocation.lat - currentLocation.lat
    dLon = targetLocation.lon - currentLocation.lon
    return math.sqrt((dLon * dLon) + (dLat * dLat)) * 1.113195e5
    # Calculate the distance using the Haversine formula

def goto(targetLocation):
    # Function to make the vehicle go to a specified target location
    distanceToTargetLocation = get_distance_meters(targetLocation, vehicle.location.global_relative_frame)
    # Calculate the initial distance to the target location
    
    vehicle.simple_goto(targetLocation)
    # Command the vehicle to go to the target location
    
    while vehicle.mode.name == "GUIDED":
        currentDistance = get_distance_meters(targetLocation, vehicle.location.global_relative_frame)
        if currentDistance < distanceToTargetLocation * 0.05:
            print("Reached target waypoint.")
            time.sleep(2)
            break
        time.sleep(1)
    # Continuously monitor the distance to the target location
    # Break the loop when the vehicle reaches within 5% of the initial distance
    
    return None

##########MAIN EXECUTABLE###########

wp1 = LocationGlobalRelative(36.00550, -95.86124, 10)
wp2 = LocationGlobalRelative(36.00607, -95.86107, 10)
wp3 = LocationGlobalRelative(36.00604, -95.86037, 10)
# Define the waypoint locations

vehicle = connectRoberto()
# Connect to the vehicle using the connectRoberto function

vehicle.parameters['WP_SPEED'] = 2
# Set the vehicle's waypoint speed parameter to 2 m/s

arm()
# Arm the vehicle and set it to GUIDED mode

goto(wp1)
goto(wp2)
goto(wp3)
# Command the vehicle to go to each waypoint sequentially

vehicle.mode = VehicleMode("RTL")
while vehicle.mode != 'RTL':
    print("Waiting for drone to enter RTL flight mode")
    time.sleep(1)
# Set the vehicle mode to RTL (Return to Launch) and wait until it is in RTL mode

print("Vehicle now in RTL mode. Driving home.")
# Print a message indicating that the vehicle is returning to the launch location

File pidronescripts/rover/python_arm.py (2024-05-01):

##########DEPENDENCIES#############
import time
import os
import platform
import sys
import socket
import exceptions
import math
import argparse
from dronekit import connect, VehicleMode,LocationGlobalRelative,APIException
#####

vehicle = connect('/dev/tty/AMA0', baud =57600, wait_ready = True)
print(str(vehicle.system_status.state))
#### Functions
def arm():
	while vehicle.is_armable!=True:
		print("Waiting for vehicle to become armable.")
		time.sleep(1)
	print("Vehicle is now armable")

	vehicle.mode = VehicleMode("GUIDED")

	while vehicle.mode!='GUIDED':
		print("Waiting for drone to enter GUIDED flight mode")
		time.sleep(1)
	print("Vehicle now in GUIDED MODE. Have fun!!")

	vehicle.armed = True
	while vehicle.armed==False:
		print("Waiting for vehicle to become armed.")
		time.sleep(1)
	print("Vehicle is now armed.")

	return None

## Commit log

2024-04-01 1st commit of 3d 'st' files
    [Hub_Spacer.stl, Wheel_Hub_260mm.stl, irobot_front_mount_v2.stl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]
2024-04-27 Change file names and added Readme's
    [CollectorTeeth.stl, Frame.stl, WheelHub.stl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]
